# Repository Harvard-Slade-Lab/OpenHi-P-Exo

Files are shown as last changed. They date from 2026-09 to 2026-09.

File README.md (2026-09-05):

# OpenHi-P Exoskeleton
Open-source, High-torque, and Portable (OpenHi-P) hip exoskeleton

Supplementary materials for "an open-source, high-torque, and portable hip exoskeleton for physically demanding locomotion."

This repository contains the STM32 controller firmware, the hardware resources, and the
host-PC human-in-the-loop optimization pipeline.

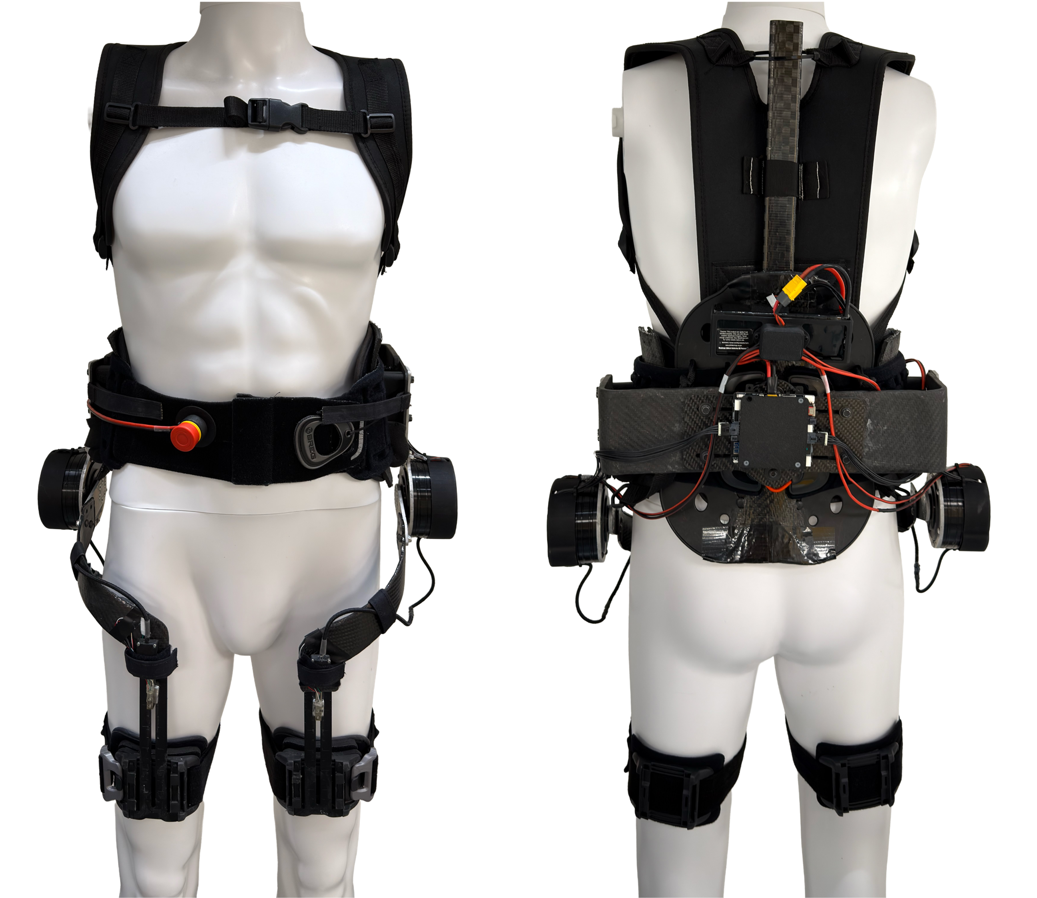
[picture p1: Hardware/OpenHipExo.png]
OpenHipExo Hardware


## Software Overview

This repository contains two pieces of software: the human-in-the-loop optimization that
runs on a host PC, which measures metabolic cost and searches for the torque profile that
minimizes it, and the embedded controller that runs on the exoskeleton, which applies that
torque profile in real time. The two communicate over Bluetooth Low Energy (BLE).

| Runs on | Directory | Language / toolchain |
|---|---|---|
| **Host PC** (Windows) — human-in-the-loop optimization | `Optimizer/` | Python, conda (`Optimizer/metcma.yml`) |
| **Exoskeleton** (STM32 microcontroller) — embedded real-time control | `Controller/` | C, STM32CubeIDE 1.17.0 |

Hardware resources for building the device are in `Hardware/`.

## Repository Structure

- `Controller/`  
  Main STM32CubeIDE C source files (core files):
  - `main.c`
  - `control_logic.c`
  - `motor_control.c` 
  - `imu_processing.c`
  - `servo_receiving.c`
  - `servo_sending.c`
  - `torque_profile.c`
  - `torque_calculation.c`
  - `can_rx_callback.c`
  - `globals.c`
  - `sd_card.c`

- `Hardware/`  
  Hardware build resources:
  - `CAD/` : CAD files
  - `Hip Exoskeleton Hardware Building Guide.pdf` : Hardware building guide  

- `Optimizer/`  
  Host-PC human-in-the-loop (HILO) optimization pipeline (Python, flat layout):
  - `main.py` : entry point (BLE + metabolics + controller + GUI)
  - `cma_optimizer.py` : CMA-ES implementation
  - `hiloMetCmaController.py` : condition sequencing and parameter update logic
  - `metabolics_collect.py`, `metabolics_extract.py` : COSMED metabolic data collection and rate estimation
  - `bleFunctions.py` : BLE client and torque-parameter packet protocol
  - `serialPlotter.py`, `param_utils.py`, `timer_manager.py` : live plotting and parameter/timing utilities
  - `metcma.yml` : pinned conda environment

## Controller (Firmware)

- Source code is organized under `Src/`.
- IDE: STM32CubeIDE (Version: 1.17.0)
- Language: C
- The firmware includes gait cycle estimation, desired torque tracking, CAN and Bluetooth communication, and SD card data logging.

## Hardware

- Hardware-related files are located in `Hardware/`.  
- Software: SolidWorks (Version: 2022).
- For detailed instructions on BoM and assembly, see `Hip Exoskeleton Hardware Building Guide.pdf`.
- Commercial off-the-shelf parts (McMaster-Carr fasteners and the CubeMars AK10-9 actuator) are
  not redistributed here. Download them from their vendors to open the full assembly; see
  `Hardware/CAD/README.md` for the part numbers and the file names the assembly expects.

## Optimizer (Host PC)

- Human-in-the-loop optimization code is located in `Optimizer/`.
- Language: Python; dependencies pinned in `Optimizer/metcma.yml`.
- Platform: Windows only (uses Win32 screen capture for the COSMED Omnia window).
- Implements CMA-ES optimization of the torque profile driven by real-time metabolic
  cost, plus the BLE parameter-update protocol to the exoskeleton controller.
- Run with `python main.py`; see `Optimizer/README.md` for installation, Tesseract OCR
  setup, usage, and simulation mode.

## License

This project is released under the MIT License; see `LICENSE`. The license covers
the firmware in `Controller/Core/`, the host-PC optimization code in `Optimizer/`,
and the hardware design files in `Hardware/CAD/` that were created for this project.

Two exceptions:

- Third-party components vendored under `Controller/Drivers/` and
  `Controller/Middlewares/` remain under their own licenses. CMSIS is Apache-2.0,
  the STM32F4xx HAL driver is BSD-3-Clause, and FatFs is under the ChaN one-clause
  BSD license. CMSIS and the HAL driver carry their own LICENSE.txt; the FatFs terms
  are stated in the headers of its source files.
- Commercial off-the-shelf CAD models are not redistributed here and are not covered
  by this license; see `Hardware/CAD/README.md`.

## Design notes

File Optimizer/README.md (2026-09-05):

# Hip-Exo-Optimization — Human-in-the-Loop (HILO) Metabolic Optimizer

PC-side software that runs **human-in-the-loop optimization** of a hip-exoskeleton
torque profile using **CMA-ES**, driven by **real-time metabolic cost** measured
from a COSMED indirect-calorimetry system. The PC ranks candidate torque profiles,
updates the CMA-ES search distribution, and streams new parameters to the
exoskeleton controller over **Bluetooth Low Energy (BLE)**.

Everything in this directory runs on the **Windows host PC**. The embedded controller
that drives the motors runs on the exoskeleton's **STM32**, from the firmware in
[`../Controller/`](../Controller/) of this same repository. The two communicate only
over BLE: the PC sends a torque-profile parameter packet, and the exoskeleton applies it.

**Affiliation:** Harvard Slade Lab
**Authors:** Jae Choi, Yinkai Dong

---

## Installation

**Platform: Windows only.** 

**1. Get the code**
```bash
git clone https://github.com/Harvard-Slade-Lab/OpenHi-P-Exo.git
cd OpenHi-P-Exo/Optimizer
```

**2. Create the conda environment** (pinned in `metcma.yml`)
```bash
conda env create -f metcma.yml
conda activate metcma
```

**3. Install Tesseract OCR** (reads numbers off the Omnia screen). Download the
preconfigured package
([Google Drive](https://drive.google.com/file/d/17DEtPNnrKnunzDX3ql_moAN2LRDF_OS9/view?usp=sharing))
and extract it into this directory so that `Tesseract-OCR/tesseract.exe` exists —
`metabolics_extract.py` resolves this path relative to its own location.

For a full hardware run you also need a BLE adapter, the exoskeleton advertising as
`HIP_EXO_MAIN`, and a COSMED metabolic cart with the Omnia window visible on screen.

---

## Usage

```bash
python main.py
```

It will:

1. Prompt for **subject number** and **body weight (kg)**.
2. Connect to the exoskeleton over BLE (device name `HIP_EXO_MAIN`) and wait until
   connected.
3. Ask you to draw three OCR regions on the Omnia window — **Time, VO2, VCO2**.
4. Open a **PyQt5 + pyqtgraph** GUI with live plots and **Start / Stop / Skip**
   buttons, then run the CMA-ES optimization of the torque profile.

- **Start** begins the CMA-ES loop; **Stop** aborts the current condition and
  ramps torque to zero (BLE stays up); **Skip** discards the current condition.
- **Resuming:** if a subject's `cmaLogFile.csv` already exists, the run reloads the
  saved CMA-ES state and continues.
- **Simulation mode (no hardware):** set `metUse = False` (and `bleUse = False`) in
  `main.py` to run the full loop on synthetic breaths.

---

## Repository structure

```
OpenHi-P-Exo/Optimizer/
│
├── main.py                    # Entry point: wires BLE + OCR + controller + GUI
├── hiloMetCmaController.py    # Central coordinator (HILOMetCmaController)
├── cma_optimizer.py           # CMA-ES optimizer
├── metabolics_collect.py      # Metabolics collection loop
├── metabolics_extract.py      # Screen capture + OCR of the Omnia display
├── bleFunctions.py            # BLE client and torque-parameter protocol
├── serialPlotter.py           # Real-time visualization (PyQtGraph)
├── param_utils.py             # Torque-profile parameter handling
├── timer_manager.py           # Qt timer helper
├── metcma.yml                 # Pinned conda environment
├── (Tesseract-OCR/)           # Installed separately, see step 3
└── README.md
```

Runtime output is written under `outcmaes/subject_<N>/` (per-condition
CSV log, pickled CMA-ES state + backups, per-breath metabolics CSVs, and plot PNGs).

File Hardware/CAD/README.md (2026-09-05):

# CAD files

This folder contains the parts designed for the OpenHi-P exoskeleton: the custom
SolidWorks parts, the `DWG/` drawings for machined parts, and the `STL/` files for
printed parts and molds.

## Commercial off-the-shelf parts are not included

The fasteners and the actuator model are commercial parts supplied by their vendors,
so their CAD files are not redistributed here. `Assmebly.SLDASM` still references them,
and SolidWorks will report them as missing until you supply them yourself.

To open the full assembly, download each part from its vendor and save it into this
folder. **SolidWorks resolves references by file name, so save each file under exactly
the name listed below** and the assembly will rebuild without further edits.

### McMaster-Carr fasteners

Download from [mcmaster.com](https://www.mcmaster.com) by searching the part number.

| Part number | Description | Save as |
|---|---|---|
| 91116A350 | 18-8 Stainless Steel Oversized Washer | `91116A350_18-8 Stainless Steel Oversized Washer.SLDPRT` |
| 91116A360 | 18-8 Stainless Steel Oversized Washer | `91116A360_18-8 Stainless Steel Oversized Washer.SLDPRT` |
| 91239A144 | Button Head Hex Drive Screw | `91239A144_Button Head Hex Drive Screw.SLDPRT` |
| 91239A232 | Button Head Hex Drive Screw | `91239A232_Button Head Hex Drive Screw.SLDPRT` |
| 91239A318 | Button Head Hex Drive Screw | `91239A318_Button Head Hex Drive Screw.SLDPRT` |
| 91251A345 | Black-Oxide Alloy Steel Socket Head Screw | `91251A345_Black-Oxide Alloy Steel Socket Head Screw.SLDPRT` |
| 91253A197 | Black-Oxide Alloy Steel Hex Drive Flat Head Screw | `91253A197_Black-Oxide Alloy Steel Hex Drive Flat Head Screw.SLDPRT` |
| 91294A192 | Black-Oxide Alloy Steel Hex Drive Flat Head Screw | `91294A192_Black-Oxide Alloy Steel Hex Drive Flat Head Screw.SLDPRT` |
| 94645A102 | High-Strength Steel Nylon-Insert Locknut | `94645A102_High-Strength Steel Nylon-Insert Locknut.SLDPRT` |
| 95947A560 | Aluminum Female Threaded Hex Standoff | `95947A560_Aluminum Female Threaded Hex Standoff.SLDPRT` |
| 97131A120 | Medium-Strength Nylon-Insert Locknut | `97131A120_Medium-Strength Nylon-Insert Locknut.SLDPRT` |
| 98093A211 | Black-Phosphate Class 10.9 Steel Hex Head Screw | `98093A211_Black-Phosphate Class 10.9 Steel Hex Head Screw.SLDPRT` |
| 98093A212 | Black-Phosphate Class 10.9 Steel Hex Head Screw | `98093A212_Black-Phosphate Class 10.9 Steel Hex Head Screw.SLDPRT` |
| 98093A310 | Black-Phosphate Class 10.9 Steel Screw | `98093A310_Black-Phosphate Class 10.9 Steel Screw.SLDPRT` |
| 98093A316 | Black-Phosphate Class 10.9 Steel Hex Head Screw | `98093A316_Black-Phosphate Class 10.9 Steel Hex Head Screw.SLDPRT` |
| 98370A009 | 18-8 Stainless Steel Oversized Washer | `98370A009_18-8 Stainless Steel Oversized Washer.SLDPRT` |

### Actuator

| Part | Source | Save as |
|---|---|---|
| CubeMars AK10-9 V2.0 | CubeMars product page | `AK10-9.SLDPRT` |

Quantities and the rest of the bill of materials are in
`../Hip Exoskeleton Hardware Building Guide.pdf`.

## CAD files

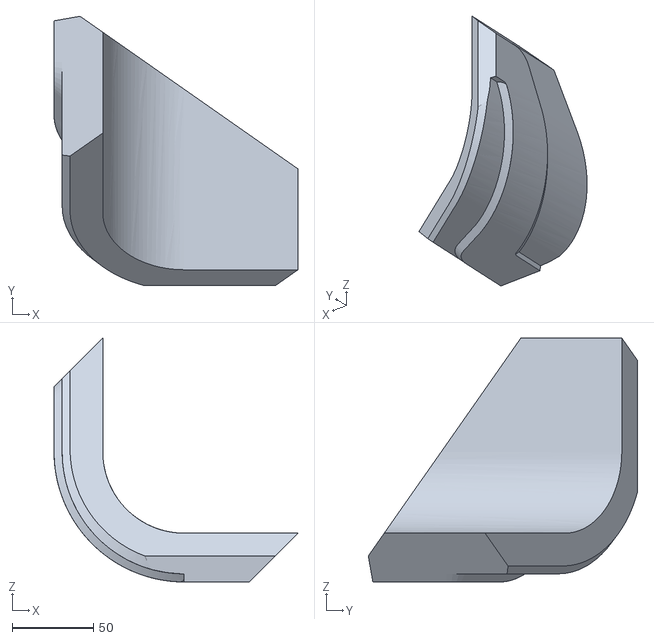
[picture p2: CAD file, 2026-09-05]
Hardware/CAD/STL/Thigh_strut_mold_left.STL
150.0 x 165.6 x 150.0

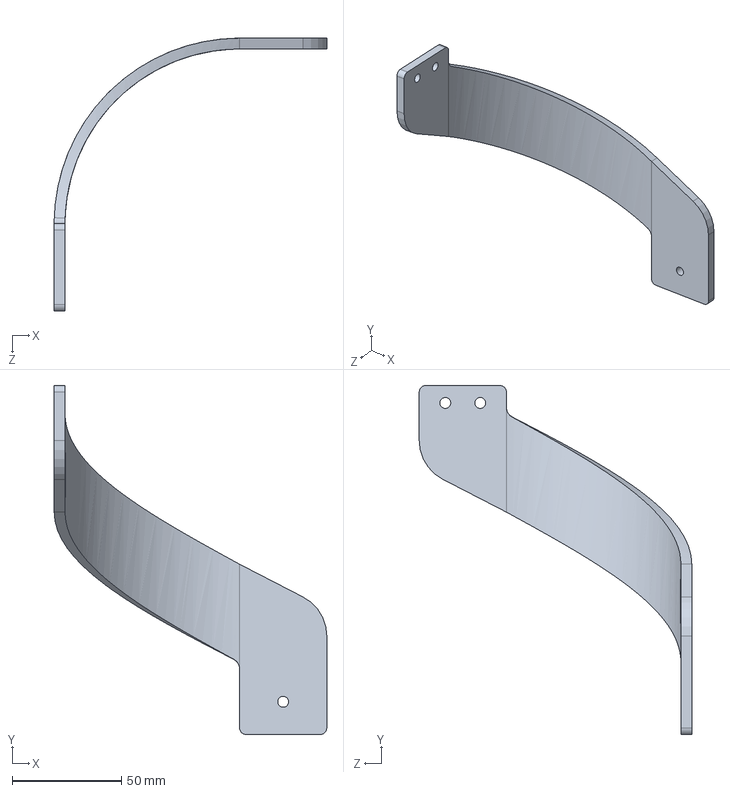
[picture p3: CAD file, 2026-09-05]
Hardware/CAD/Thigh_strut_left.SLDPRT
125.0 x 160.0 x 125.0 mm

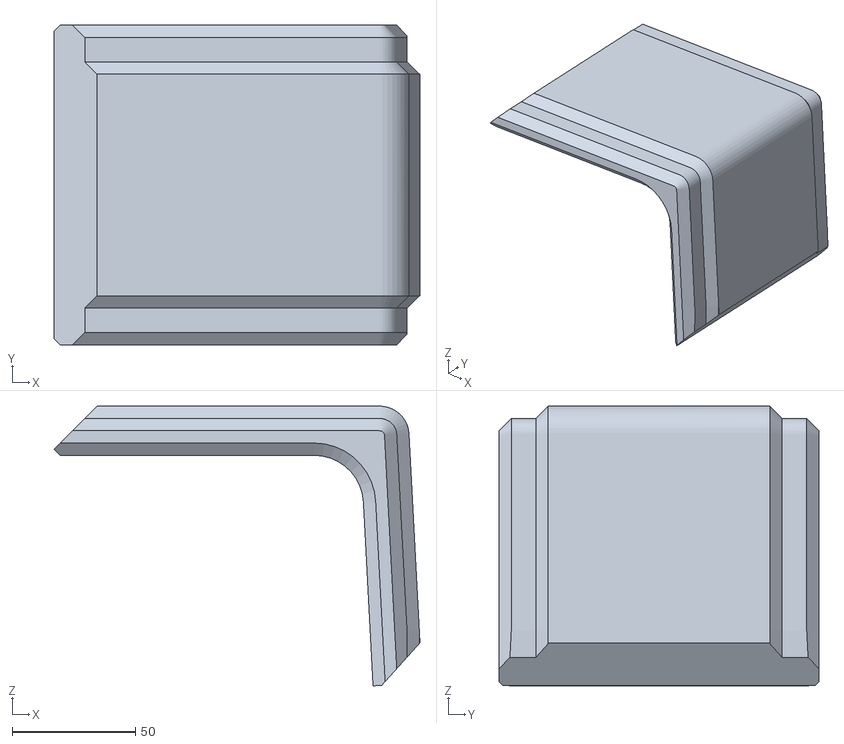
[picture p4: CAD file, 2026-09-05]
Hardware/CAD/STL/Waist_c_frame_mold.STL
148.7 x 130.0 x 113.6

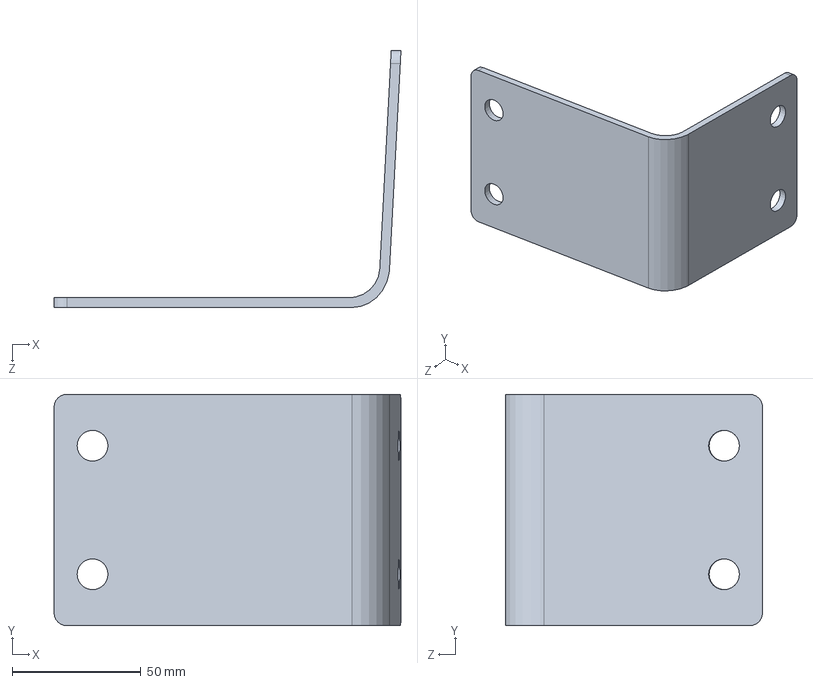
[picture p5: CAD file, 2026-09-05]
Hardware/CAD/Waist_c_frame.SLDPRT
135.0 x 90.0 x 100.0 mm

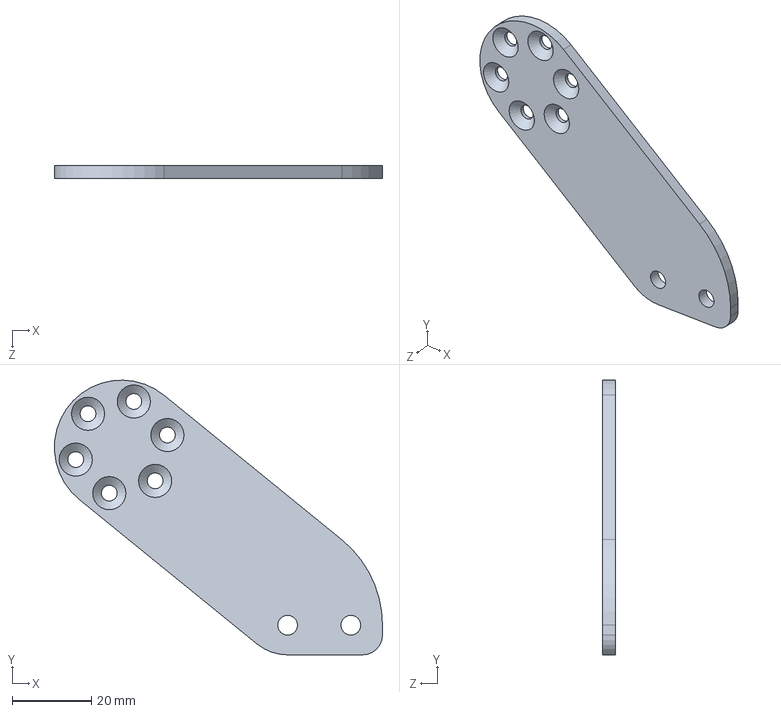
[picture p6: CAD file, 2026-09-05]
Hardware/CAD/Motor_rotor_left.SLDPRT
83.0 x 69.5 x 3.17 mm

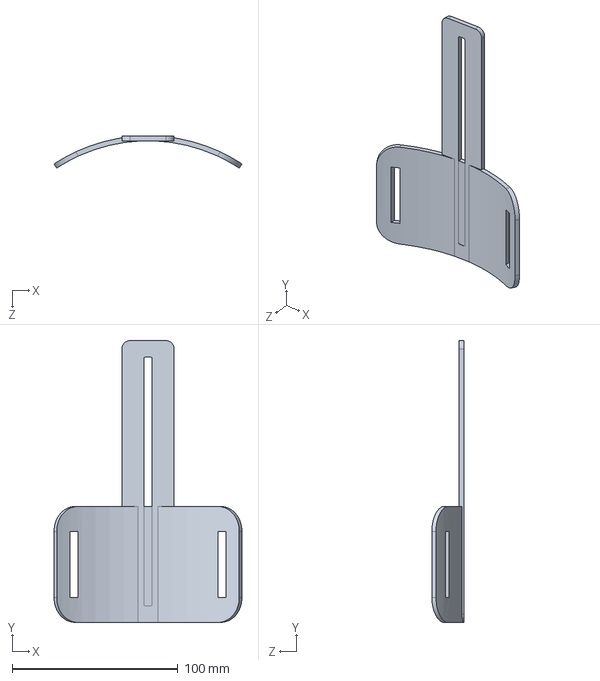
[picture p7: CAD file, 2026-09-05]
Hardware/CAD/Thigh_brace.SLDPRT
113.3 x 170.0 x 19.5 mm

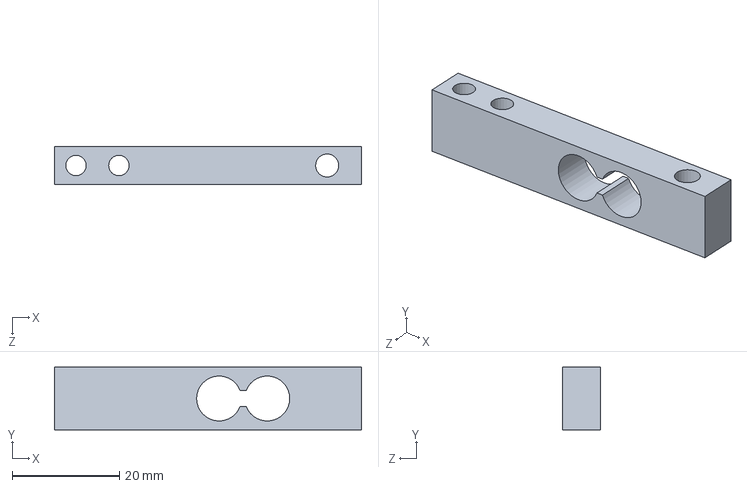
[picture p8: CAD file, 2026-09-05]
Hardware/CAD/Loadcell.SLDPRT
57.2 x 11.7 x 7.00 mm

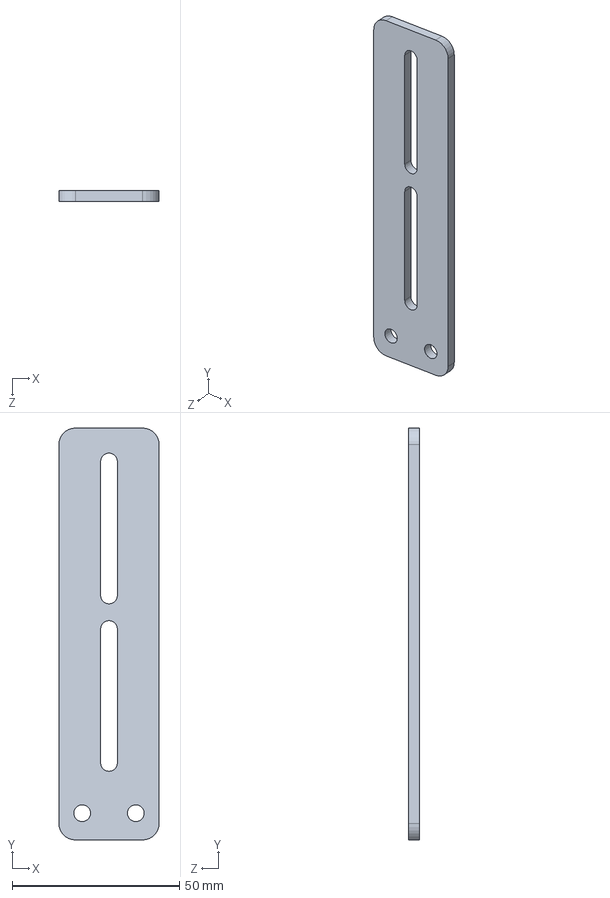
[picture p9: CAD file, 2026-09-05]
Hardware/CAD/Motor_stator_strut.SLDPRT
30.0 x 123.0 x 3.17 mm

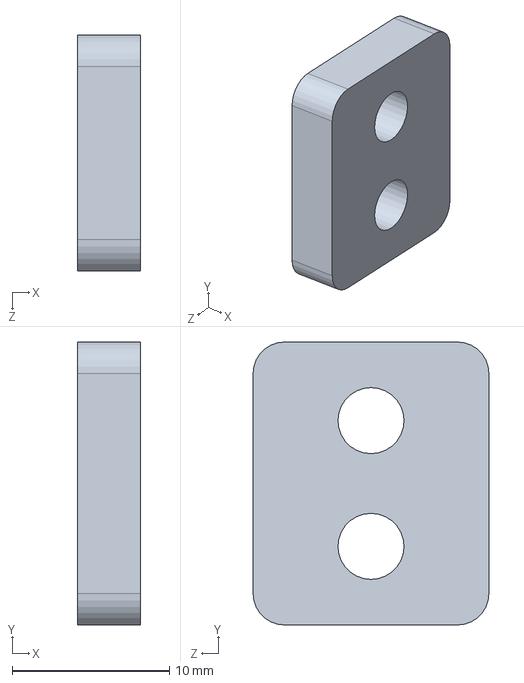
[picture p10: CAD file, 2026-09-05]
Hardware/CAD/Loadcell_bumper_t.SLDPRT
4.00 x 18.0 x 15.0 mm

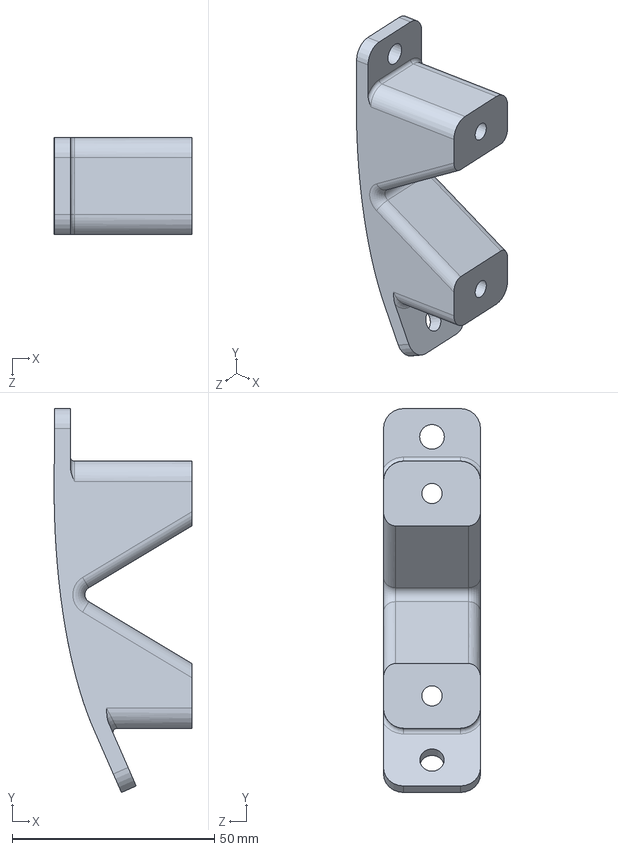
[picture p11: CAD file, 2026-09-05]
Hardware/CAD/Waist_side_connector.SLDPRT
34.0 x 94.9 x 24.0 mm

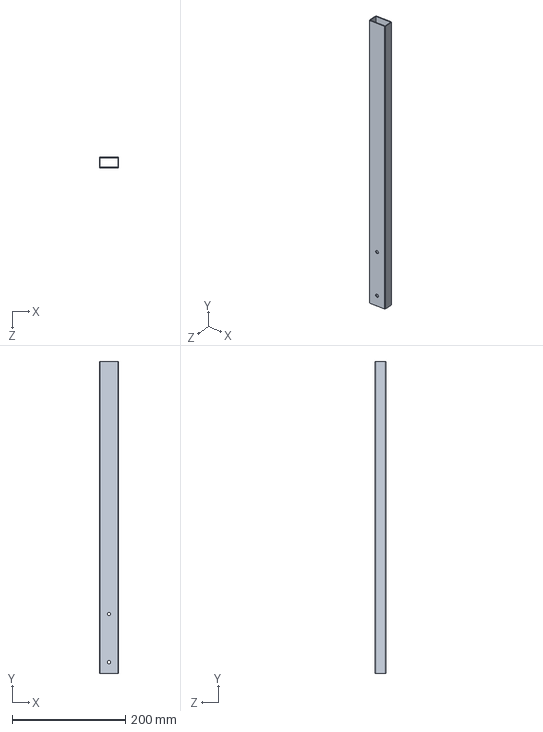
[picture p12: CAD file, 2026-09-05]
Hardware/CAD/Back_strut.SLDPRT
34.3 x 550.0 x 19.1 mm

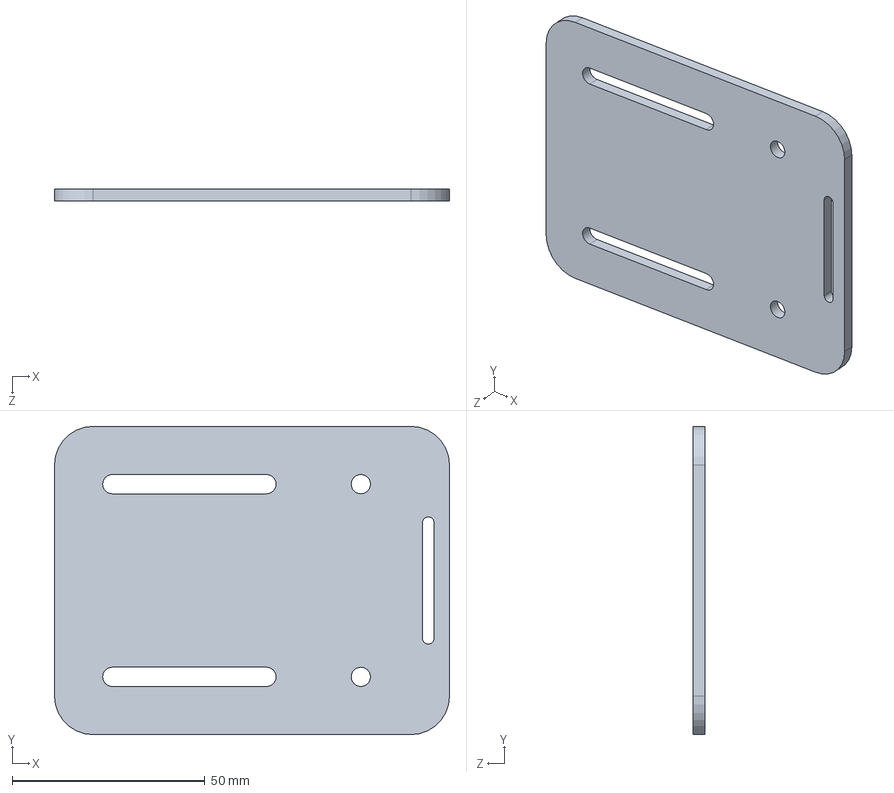
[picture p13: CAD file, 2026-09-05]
Hardware/CAD/Waist_side_plate.SLDPRT
102.5 x 80.0 x 3.17 mm

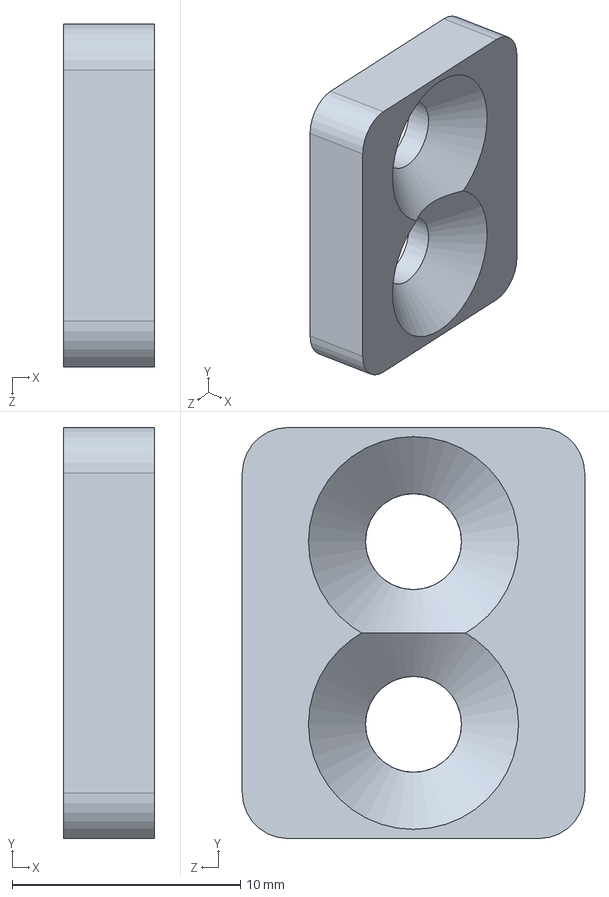
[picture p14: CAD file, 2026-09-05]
Hardware/CAD/Loadcell_bumper_b.SLDPRT
4.00 x 18.0 x 15.0 mm

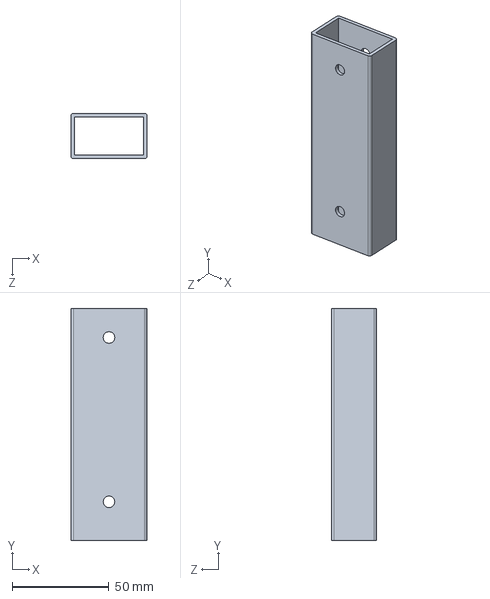
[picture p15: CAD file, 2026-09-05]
Hardware/CAD/Cf_tube_hole_reference.SLDPRT
39.5 x 120.0 x 23.5 mm

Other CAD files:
Hardware/CAD/DWG/Loadcell_bumper.DWG
Hardware/CAD/DWG/Motor_rotor.DWG
Hardware/CAD/STL/Thigh_strut_mold_right.STL
Hardware/CAD/Motor_rotor_right.SLDPRT
Hardware/CAD/DWG/Motor_stator.DWG
Hardware/CAD/DWG/Motor_stator_strut.DWG
Hardware/CAD/DWG/Waist_back_plate.DWG
Hardware/CAD/DWG/Waist_side_plate.DWG
Hardware/CAD/Insert.SLDPRT
Hardware/CAD/Motor_stator.SLDPRT
Hardware/CAD/STL/Cf_tube_hole_reference.STL
Hardware/CAD/STL/Insert.STL
Hardware/CAD/STL/Waist_side_connector.STL
Hardware/CAD/Thigh_strut_right.SLDPRT
Hardware/CAD/Waist_back_plate.SLDPRT

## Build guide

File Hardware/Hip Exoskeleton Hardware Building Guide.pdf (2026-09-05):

# Hardware building guide for an Open-source, High-torque, and Portable (OpenHi-P) hip exoskeleton

Jae-Ryeong Choi, Yinkai Dong, Catherine Rohner, and Patrick Slade

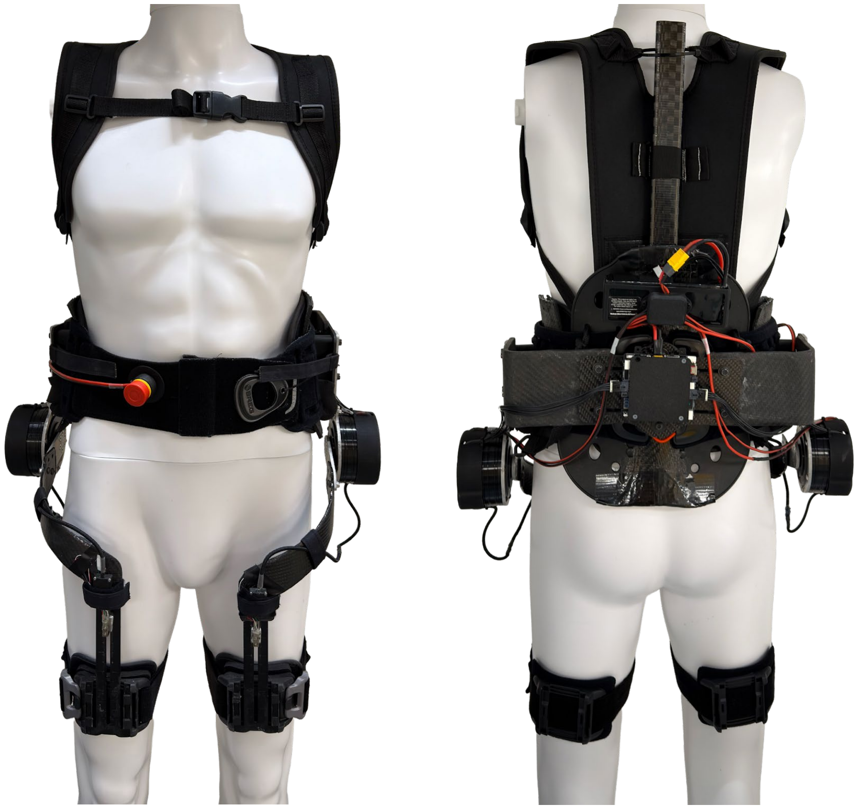
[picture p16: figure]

# Bill of materials

## Commercially available goods

COM-1: Vest: Smith Performance Sprayer (https://www.amazon.com/Smith-Performance-Sprayers-182943-Backpack/dp/B01MY1YLJZ?hvadid=193139379506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) ($39.49) x 1
COM-2: Back brace: Nvorliy LSO Lower Back Brace (https://www.amazon.com/Nvorliy-Lower-Back-Brace-Decompression/dp/B09MPKXBKF) ($38.99) x 1 COM-3: Hip brace: Breg T-scope hip brace (https://www.breg.com/products/hip-bracing/hip-bracing-post-op/t-scope-hip-brace/) (used) x 2

## Electronics and power

ELE-1: Motor: Cubemars AK10-9 V2.0 KV60 (https://www.cubemars.com/product/ak10-9-v2-0-kv60-robotic-actuator.html) ($798.90) x 2 ELE-2: Load cell: SMD S230 (https://www.smdsensors.com/products/type/s230-low-profile-load-cell/?highlight=s230) ($210.94) x 2
ELE-3: IMU: Xsens MTi-3-5A-T (https://www.digikey.com/en/products/detail/xsens-a-movella-brand/MTI-3-5A-T/18718048) ($359) x 2
ELE-4: Controller: STM32 Nucleo-F446RE (https://www.digikey.com/en/products/detail/stmicroelectronics/NUCLEO-F446RE/5347712) ($14.85) x 1
ELE-5: Battery: MaxAmps LiPo 3250mAh 6S 22.2v Battery Pack (https://maxamps.com/collections/6s-lipo-battery-22-2v/products/lipo-3250-6s-22-2v-battery-pack) ($210) x 1
ELE-6: Emergency stop: Galco XA1E-BV3SG01RH (https://www.galco.com/xa1e-bv3sg01rh-idec.html) ($44.93) x 1

## Items for fabrication

FAB-1: Carbon fiber plate: DragonPlate EconomyPlate™ ~ 1/8" x 24" x 24" (https://dragonplate.com/economyplate-solid-carbon-fiber-sheet-3mm-x-24-x-24) ($337.55) FAB-2: Carbon fiber tube: Rectangle - Spread Tow Fabric - 0.625 x 1.25 - 0.75 x 1.35 x 66 inch (https://www.rockwestcomposites.com/25502-im.html) ($206.99)
FAB-3: Aluminum sheet: 7075-T6 aluminum sheet, 0.16″ × 12″ × 12″ (https://www.mcmaster.com/products/aluminum-slabs/material%7E7075-aluminum/thickness%7E0-160/width%7E12/length%7E12/length%7E1-ft/) ($54.9)
FAB-4: Velcro: Extra-Wide Hook and Loop
A. Loop: VELCRO Brand Sew On Loop, 4″ x 900″ (https://www.hookandloop.com/brands/velcro/sew-on) ($ 76)
B. Hook: VELCRO Brand Sew On Hook, 4″ x 900″ (https://www.hookandloop.com/brands/velcro/sew-on) ($ 76)
FAB-5: Foam Padding: Adhesive-backed Neoprene Sheet, 12″ × 59″ × 1/2″ (https://www.amazon.com/FONUNO-Adhesive-Insulation-Neoprene-Projects/dp/B0FPFT157Q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) ($26.99) FAB-6: Carbon fiber sheet: Carbon Fiber Fabric 2x2 Twill 6k 11oz/372gsm (https://www.compositeenvisions.com/Carbon-Fiber-Fabric-2x2-Twill-6k-11oz-373gsm-Commercial-Grade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) ($42.48) FAB-7: Epoxy resin: WEST SYSTEM 105B Bundle with 205B Fast Epoxy Hardener (https://www.amazon.com/System-105-B-Epoxy-Hardener-Metering/dp/B07JKYCV8G) ($203.22)
FAB-8: Vacuum bag: Vacuum Compression Space Saving Storage Bags (https://www.amazon.com/AmazonBasics-Vacuum-Compression-Storage-Bags/dp/B07RSCK4XS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) ($17.48) FAB-9: Peel ply: ZENFUN Cloth Carbon Fiber Fiberglass 5 Yard 30 Inch (https://www.amazon.com/ZENFUN-Fiber-Fiberglass-Temperature-Compatible/dp/B0FMRNBF7K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) ($15.99) FAB-10: Breather-bleeder fabric: Fibre Glast (polyester), ~60" × 36" (1 yard) (https://www.amazon.com/Fibre-Glast-Ounce-Breather-Bleeder/dp/B015NM0B8K) ($13.95) FAB-11: Release film: Fibre Glast Low Temp Release Film (https://www.amazon.com/Fibre-Glast-Temperature-Release-Film/dp/B015NM4OEW?sp_csd=d2lkZ2V0TmFtZT1zcF9hdGY) ($10.95)

## Fasteners

Standoff:
STF-1: Lightweight Aluminum Female Threaded Hex Standoff (https://www.mcmaster.com/95947A560/)
Bolts:
BLT-1: Flanged Button Head Screws, M6 x 1.00 mm Thread, 35mm Long (https://www.mcmaster.com/92137A550/) BLT-2: Hex Head Screw Flanged, M5 x 0.8 mm Thread Size, 16 mm Long (https://www.mcmaster.com/98093A316/) BLT-3: Button Head Hex Drive Screw, Black-Oxide Alloy Steel, M5 x 0.80 mm Thread, 6 mm Long (https://www.mcmaster.com/91239A220/)
BLT-4: Nylon Pan Head Phillips Screws M3 x 0.50 mm Thread, 25mm (https://www.mcmaster.com/92492A723/) BLT-5: Button Head Hex Drive Screw, Black-Oxide Alloy Steel, M6 x 1.00 mm (https://www.mcmaster.com/91239A318/)

Thread, 12 mm Long (https://www.mcmaster.com/91239A318/)
BLT-6: Black-Oxide Alloy Steel Hex Drive Flat Head Screw 8-32 Thread Size, 3/4" Long (https://www.mcmaster.com/91253a197/)
BLT-7: Black-Oxide Alloy Steel Socket Head Screw 10-32 Thread Size, 3/4" Long (https://www.mcmaster.com/91251A345/) BLT-8: Zinc-Plated Alloy Steel Hex Drive Flat Head Screw M4 x 0.7 mm Thread Size, 10 mm Long (https://www.mcmaster.com/91263A828/)
BLT-9: Button Head Hex Drive Screw Black-Oxide Alloy Steel, M4 x 0.70 mm Thread, 10 mm Long (https://www.mcmaster.com/91239A144/)
BLT-10: Black-Phosphate Class 10.9 Steel Hex Head Screw Flanged, M5 x 0.8 mm Thread Size, 25 mm Long (https://www.mcmaster.com/98093A212/)
Nuts:
NUT-1: Zinc-Plated Steel M5 x 0.8 mm (https://www.mcmaster.com/94645A102/)
NUT-2: Nylon Hex Nut M3 x 0.5 mm Thread (https://www.mcmaster.com/93800A400/)
Washer:
WSR-1: Stainless Steel Oversized Washer, 5.3 mm ID, 15.0 mm OD (https://www.mcmaster.com/91116A350/) WSR-2: Stainless Steel Oversized Washer, 6.4 mm ID, 18.0 mm OD (https://www.mcmaster.com/91116A360/) WSR-3: Stainless Steel Oversized Washer 0.172" ID, 0.375" OD (https://www.mcmaster.com/98370A009/)

# Fabrication methods

## Carbon-fiber composite molding

Components:
- CF-1: Thigh_strut_mold_left.stl, Thigh_strut_mold_right.stl
- CF-2: Waist_c_frame_mold.stl
- CF-3: COM-2 reinforcement
Steps:
1. Print molds (Thigh_strut_mold_left.stl, Thigh_strut_mold_right.stl, and Waist_c_frame_mold.stl). Cover all mold surfaces with release film to prevent epoxy adhesion and to facilitate demolding after curing.
2. Cut the carbon fiber sheets, peel ply, and breather fabric to the required geometries. Apply two layers of peel ply to CF-1 and CF-2 to ensure clean release and a consistent surface finish. For CF-3, apply one layer of peel ply. In all cases, apply a single layer of breather fabric to enable air evacuation and absorb excess resin during vacuum compaction.
3. Prepare the epoxy using WEST SYSTEM 105B resin with 205B fast hardener. Mix the components according to the manufacturer’s recommended ratio and stir thoroughly until the mixture is homogeneous to ensure consistent curing. Perform all layups in a chemical fume hood under vacuum bagging conditions to ensure proper resin handling and adequate laminate compaction.
4. For CF-1 and CF-2, first place a layer of peel ply onto the prepared mold surface, then apply a thin, uniform epoxy layer. Use 8 carbon fiber layers for CF-1, 16 layers for CF-2. For CF-3, apply epoxy directly to the central support region of the COM-2 brace, then bond two carbon fiber sheets to both the anterior and posterior surfaces. Use 4 layers for each side of CF-3.
5. Apply carbon fiber sheets sequentially, brushing epoxy between layers to ensure complete saturation and adequate interlaminar bonding. Use a balanced 0°/90°/±45° fiber orientation sequence to provide multidirectional stiffness and improved structural performance under combined loading. After placing the final carbon fiber layer, apply a top layer of peel ply to facilitate unmolding.
6. Cover the laminate stack with breather fabric and enclose it in vacuum bagging film. Seal the vacuum bag and apply vacuum pressure to ensure uniform compaction across the laminate thickness. Inspect the system for leaks and confirm that the bag conforms tightly to the mold geometry. Cure the composite under continuous vacuum at room temperature overnight.
7. Once curing is complete, release the vacuum and remove the composite parts from the bag. Remove the breather fabric, peel ply, and release film, then trim excess material from the edges. Achieve the final edge geometry by grinding and hand-drilling mounting holes according to specification.

## Waterjet cutting

Components:
- Carbon fiber plate (FAB-1, 0.125 inch)
- CUT-CF-1: Waist_back_plate.dwg x 2
- CUT-CF-2: Waist_side_plate.dwg x 2
- Aluminum plate (FAB-3, 0.16 inch)
- CUT-AL-1: Motor_rotor.dwg x 2
- CUT-AL-2: Motor_stator.dwg x 2
- CUT-AL-3: Motor_stator_strut.dwg x 2
- CUT-AL-4: Loadcell_bumper.dwg x 4

## CNC machining

Components:
- Aluminum 7075
- CNC-1: Insert.stl x 4
- After printing, press-fit two NUT-1s into the designated hexagonal recesses.

## 3D-printing

Components:
- 3DP-1: Waist_side_connector.stl x 2
- After printing, press-fit two NUT-1s into the designated hexagonal recesses. Settings:
- Printer: Bambu Lab P1S
- Setup: 0.4 mm nozzle, textured PEI build plate, Infill 100%.
- Print material: Carbon fiber-reinforced PLA (PLA-CF).

## Sewing

Components:
- COM-1
Steps:
1. Remove the waist parts of COM-1. Sew nylon webbing horizontally along both sides of COM-1 to create reinforced attachment points. Secure zip ties around the back rod and the webbing bands to minimize spacing and restrict movement of the carbon fiber rod.
2. Sew an additional strip of nylon webbing along the posterior centerline to guide and stabilize the carbon fiber rod. Reuse the trimmed webbing from the initial fabric removal step for this purpose. Maintain a narrow webbing channel profile to ensure a tight fit with the carbon fiber rod.
3. Sew Velcro to the bottom of COM-1 to complete the lumbar support interface.

## Manual machining

Components:
- Carbon fiber tube cutting (FAB-2)
- CUT-CF-3
■ Cut FAB-2 to 55 cm.
■ Drill two through-holes using the reference model (Cf_tube_hole_reference.stl)
- Load cell tapping (ELE-2)
- Tap two holes for an 8-32 thread (0.15 inch diameter).
- Tap one hole for a 10-32 thread (0.17 inch diameter).
- Countersinking (CUT-AL-2)
- Countersink the flat-head bolt holes.
- COM-2 post-processing
- Drill two M6 holes along the centerline of the brace, spaced 85 mm apart, with the lower hole located 95 mm from the bottom edge.
- Attach the Velcro to the lumbar support side of COM-2.

# Assembly steps

## A1. Back brace and strut integration

Parts needed:
- CUT-CF-3
- COM-2
- BLT-1 x 2
- STF-1 x 2
Steps:
1. Secure CUT-CF-3 to
COM-2 using two BLT-1s and two STF-1s.
2. Trim FAB-4-A to match
the geometry of COM-2-
A and COM-2-B.
3. Bond FAB-4-A to COM-2
to provide a compliant

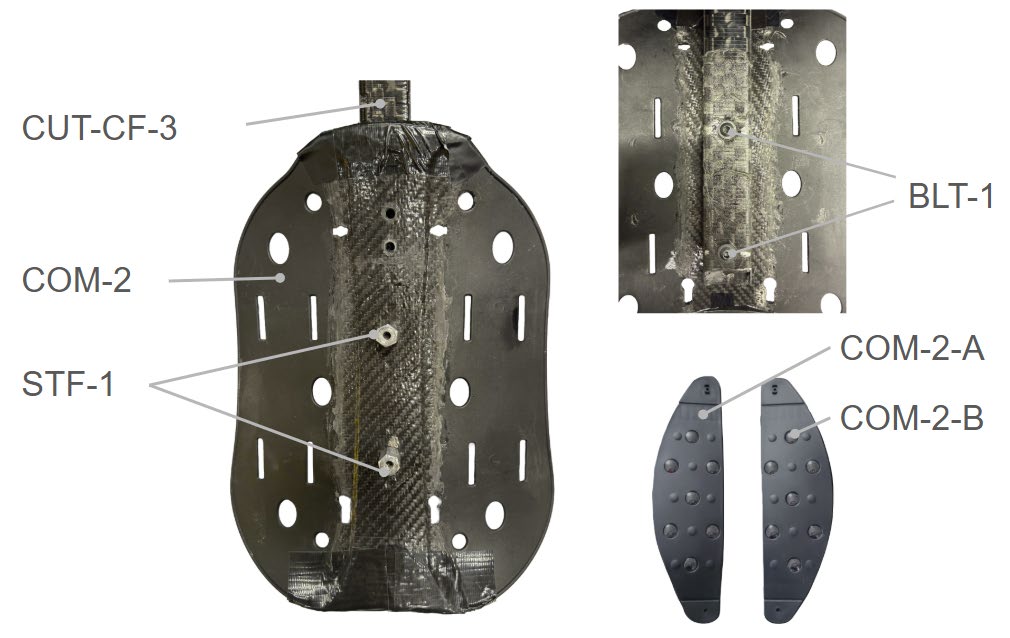
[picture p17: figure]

contact surface and improve load distribution at the lumbar interface.

## A2. A1 and vest integration

Parts needed:
- A1
- COM-1
Steps:
1. Insert CUT-CF-3 (A1) into COM-1.
2. Adjust its vertical position to match the wearer’s torso
length to ensure proper fit and comfort.
3. Thread the COM-1 shoulder
strap webbing through the

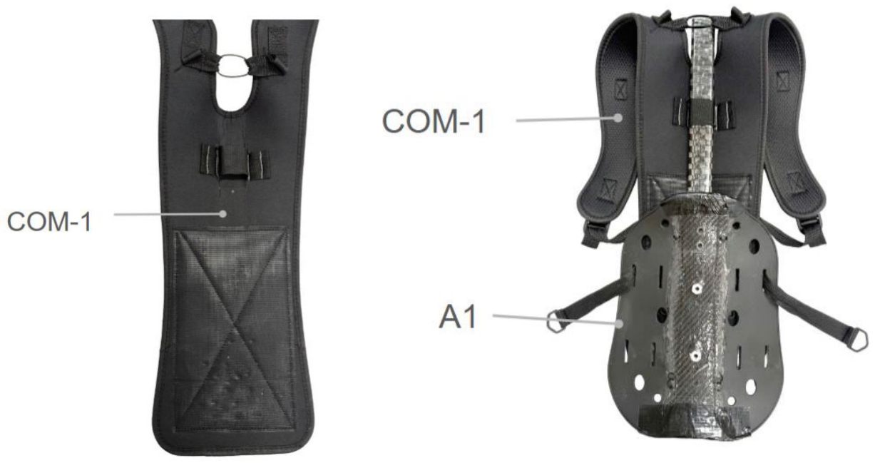
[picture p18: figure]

outer slot on COM-2 (A1) to secure the brace assembly to the vest and maintain alignment during wear.

## B1. Carbon fiber parts integration

Parts needed:
- CUT-CF-1 x 2
- CUT-CF-2 x 2
- CF-2 x 2
- CNC-1 x 4
- WSR-1 x 8
- BLT-2 x 8

Steps:

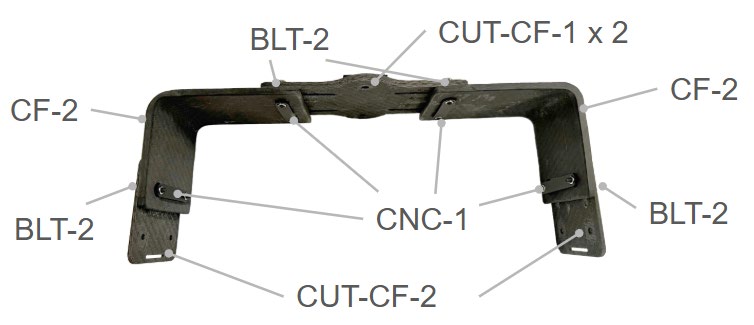
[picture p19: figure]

1. Install the CNC-1 inserts into the corresponding CF-2 components to create reinforced threaded interfaces.
2. Fully overlap and align the two CUT-CF-1 plates to form the central plate structure.
3. Secure each side of this assembly to the CF-2 plates using BLT-2 and WSR-1.
4. Attach the two CUT-CF-2 plates to the opposite sides of the CF-2 plates using the remaining BLT-2 and WSR-1 to complete the carbon fiber plate subassembly.

## C1. Soft waist cover integration

Parts needed:
- COM-3 x 1
- FAB-5
- 3DP-1 x 2
- BLT-3 x 4
- BLT-4 x 4
- NUT-2 x 4

Steps:
1. Secure 3DP-1 to the cavity of
COM-3 using BLT-3.

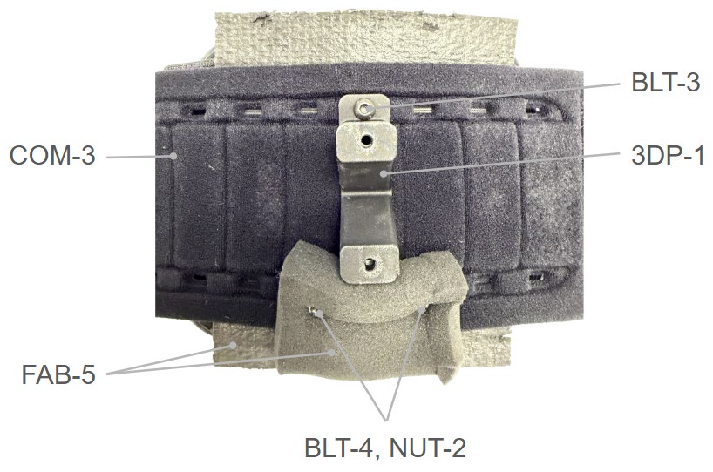
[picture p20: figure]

2. Trim FAB-5 and wrap it around the edge and lower portion of COM-3 to cover both the inner and outer surfaces and to improve pressure distribution during wear.
3. Secure the wrapped FAB-5 layer at the bottom holes using BLT-4 and NUT-2.

## C2. A2, B1, and C1 integration

Parts needed:
- A2
- C1
- B1
- BLT-5 x 2
- WSR-2 x 2

Steps:

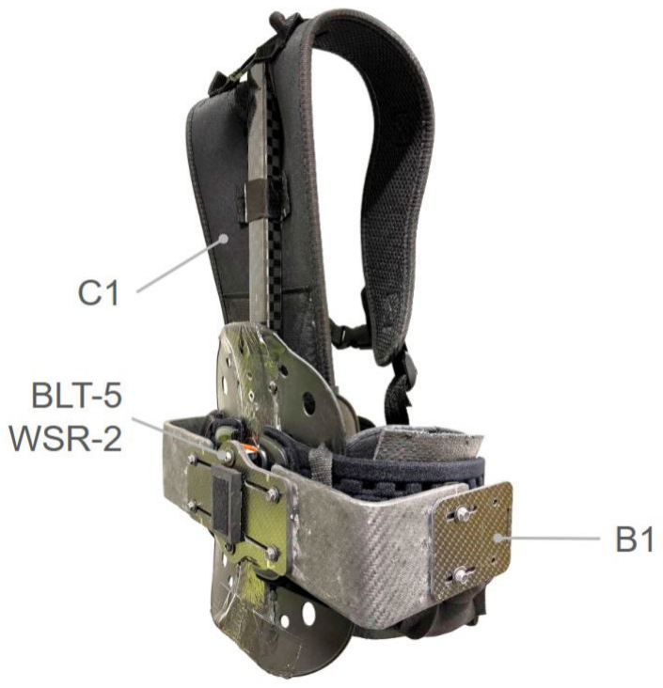
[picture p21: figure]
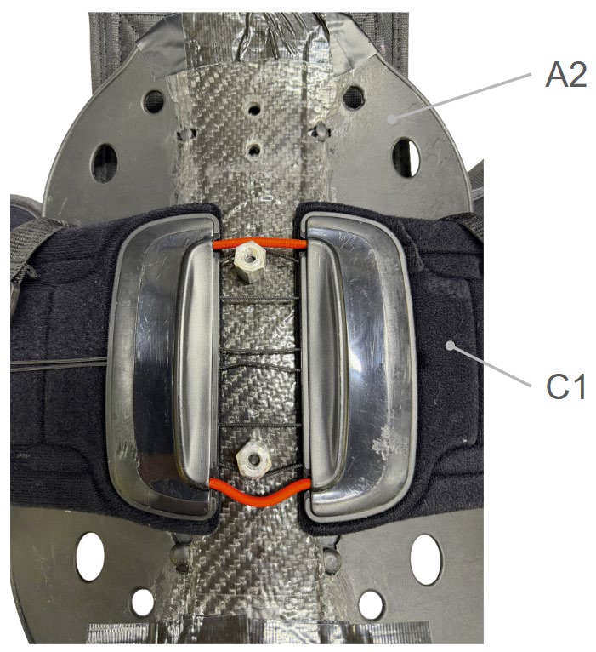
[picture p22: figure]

1. Position C1 on top of A2. Ensure that the STF-1 does not interfere with or compress the routed wires during installation.
2. Secure CUT-CF-1 and STF-1 using BLT-5 and WSR-2.

## D1. Thigh parts integration

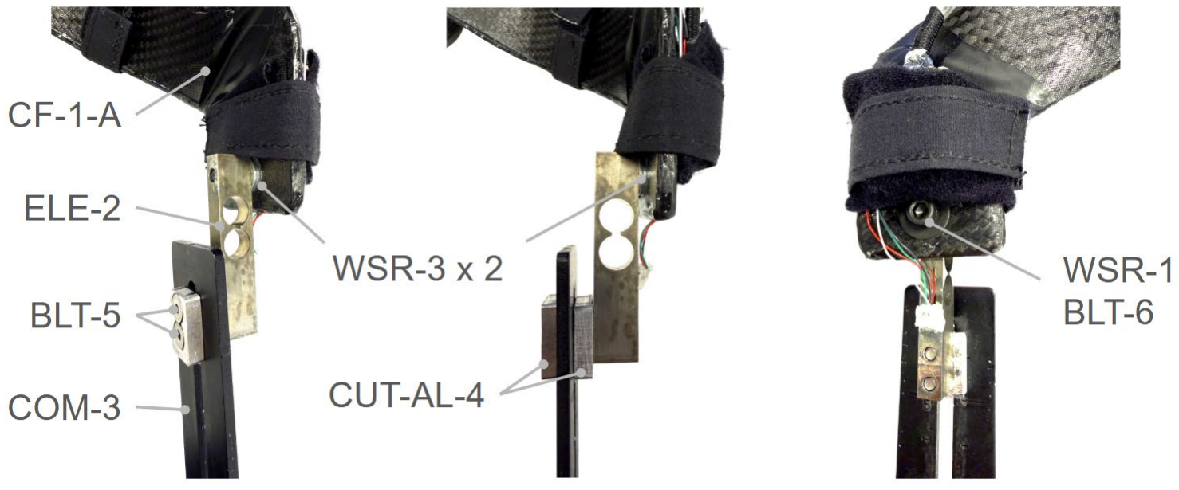
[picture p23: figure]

Parts needed:
- CF-1-A
- CF-1-B
- COM-3
- ELE-2 x 2
- CUT-AL-4 x 4
- BLT-5 x 4
- BLT-6 x 2
- WSR-1 x 2
- WSR-3 x 4
Steps:
1. Stack two WSR-3 in sequence on the side of CF-1-A.
2. Insert BLT-6 through both WSR-3 and CF-1-A, then tighten it into the thread of ELE-2.

## D2. D1 and motor integration

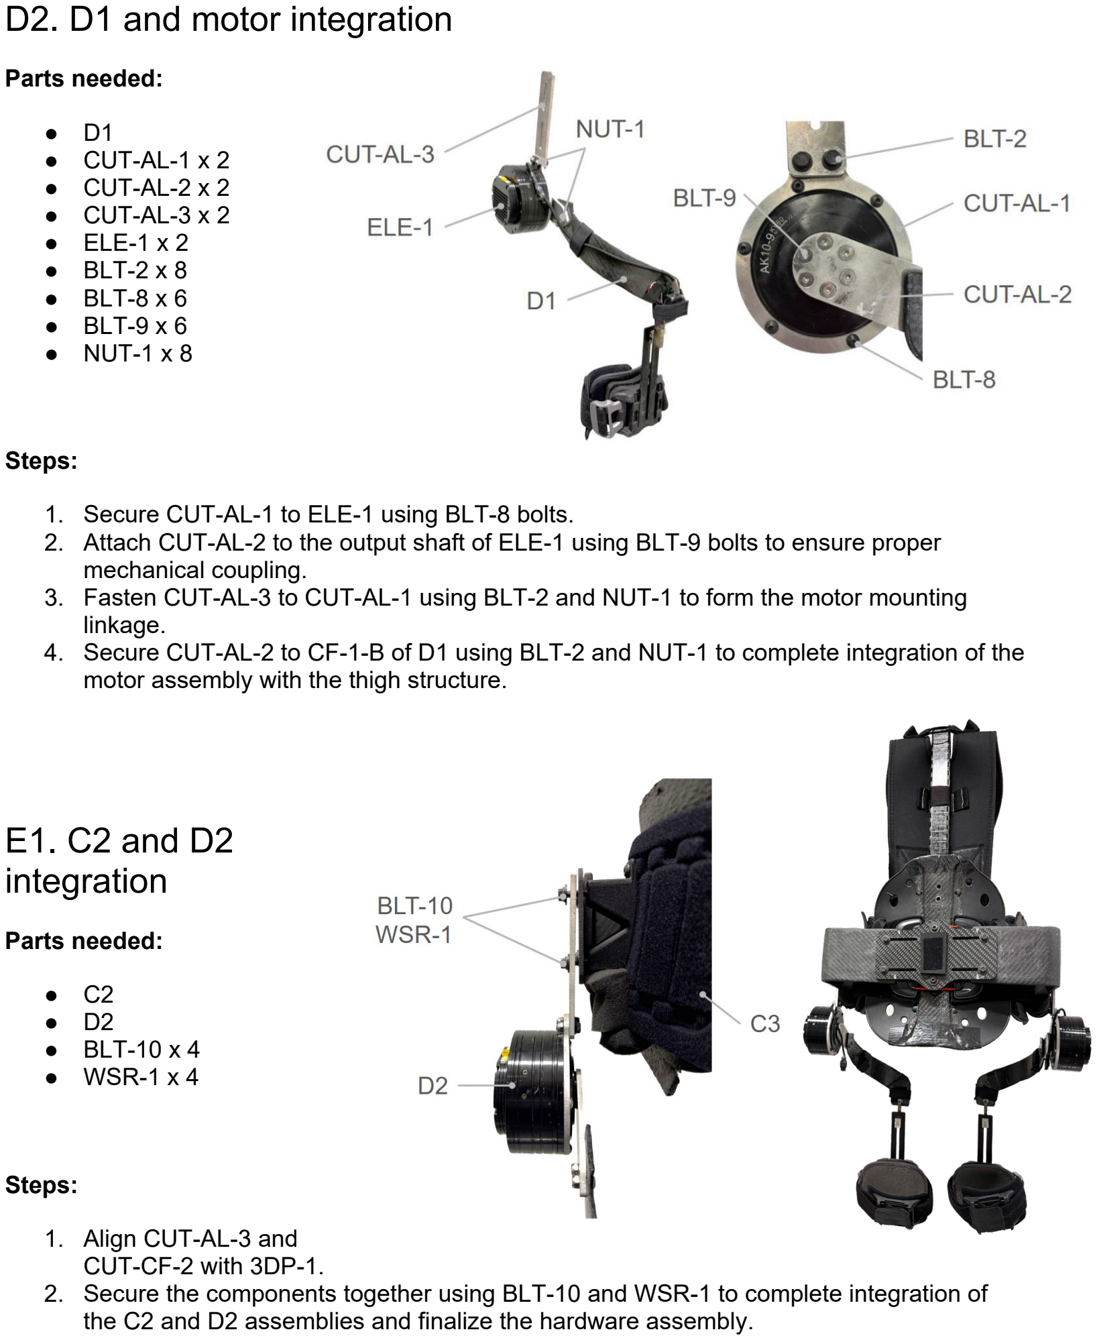
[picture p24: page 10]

Parts needed:
- D1
- CUT-AL-1 x 2
- CUT-AL-2 x 2
- CUT-AL-3 x 2
- ELE-1 x 2
- BLT-2 x 8
- BLT-8 x 6
- BLT-9 x 6
- NUT-1 x 8

Steps:
1. Secure CUT-AL-1 to ELE-1 using BLT-8 bolts.
2. Attach CUT-AL-2 to the output shaft of ELE-1 using BLT-9 bolts to ensure proper mechanical coupling.
3. Fasten CUT-AL-3 to CUT-AL-1 using BLT-2 and NUT-1 to form the motor mounting linkage.
4. Secure CUT-AL-2 to CF-1-B of D1 using BLT-2 and NUT-1 to complete integration of the motor assembly with the thigh structure.

## E1. C2 and D2 integration

Parts needed:
- C2
- D2
- BLT-10 x 4
- WSR-1 x 4

Steps:
1. Align CUT-AL-3 and
CUT-CF-2 with 3DP-1.
2. Secure the components together using BLT-10 and WSR-1 to complete integration of the C2 and D2 assemblies and finalize the hardware assembly.

# Electronics

The OpenHi-P control system is divided into a host-computer layer and an embedded real-time layer.
1. The host PC runs the human-in-the-loop optimization software in the Optimizer directory of the OpenHi-P-Exo repository.
2. The embedded controller runs the C firmware in the Controller directory of the OpenHi-P-Exo repository.
These two software systems communicate through the HM-10 Bluetooth module.

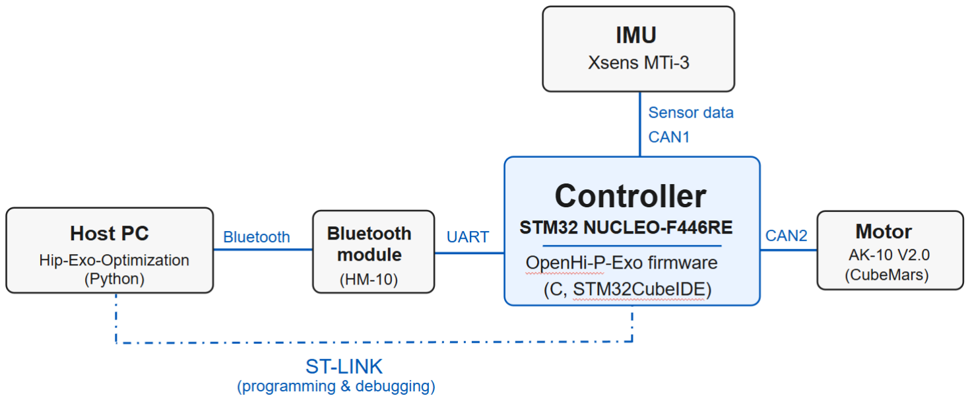
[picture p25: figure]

During an optimization condition:
1. The host PC generates a candidate hip-torque profile and sends the profile over Bluetooth Low Energy.
2. The HM-10 converts the wireless data to a 3.3 V UART stream.
3. The STM32 receives the packet through USART1, updates the active torque profile, estimates gait phase from the sensor signals, and sends motor-current commands through CAN2.

## MCU connection

The embedded controller is the STM32F446RE on the NUCLEO-F446RE development board. The firmware project was created for STM32CubeIDE 1.17.0 and uses the STM32 HAL and FatFs libraries included in the Controller directory. The system clock is configured at 168 MHz.

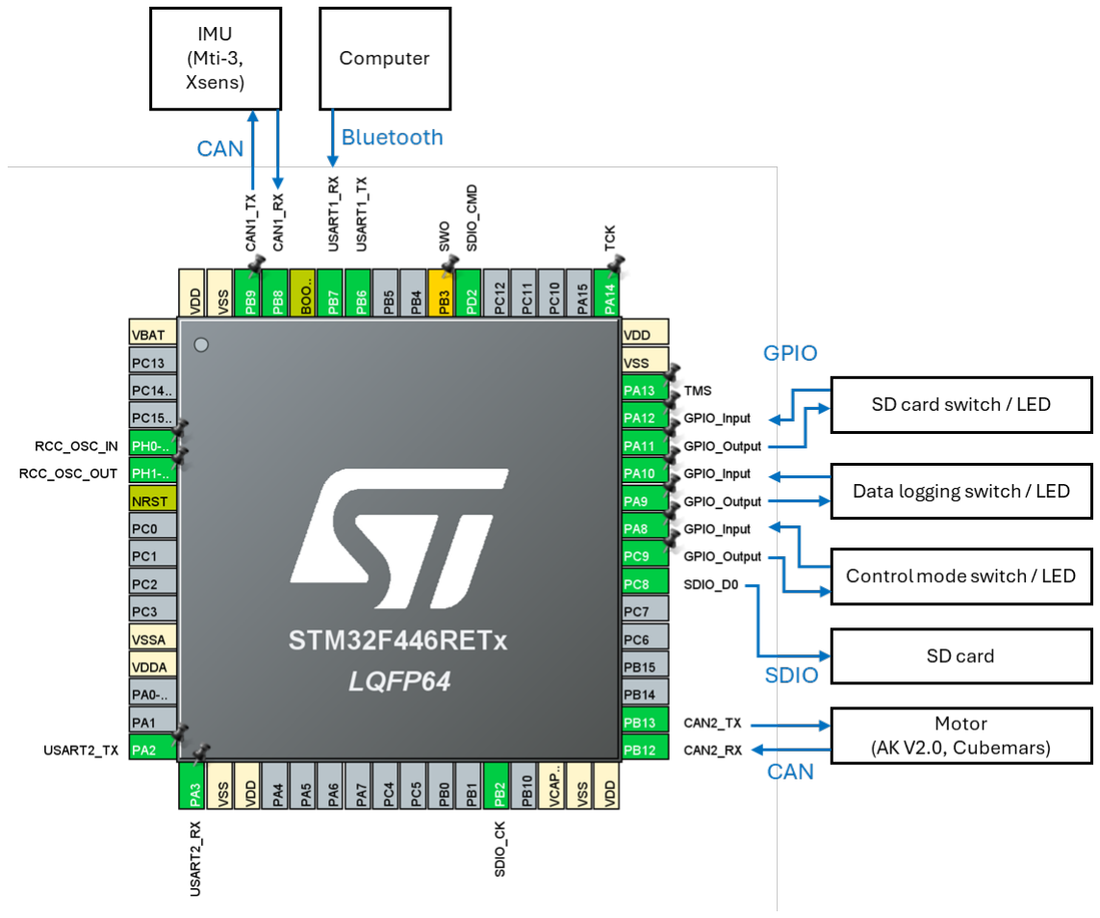
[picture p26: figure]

## Import, build, and flash the firmware

The firmware runs on the STM32, not on the host PC. Use the following procedure to program the controller:
1. Clone the repository. Clone OpenHi-P-Exo and open the Controller directory.

### 2. Import the project. In STM32CubeIDE, select File > Import > Existing Projects

into Workspace and choose the Controller directory.
3. Build. Select the Debug or Release configuration and build the project.

### 4. Connect ST-LINK. Connect the NUCLEO-F446RE to the PC through the onboard

ST-LINK USB connector.

### 5. Flash and test. Use Run or Debug to program the MCU. Confirm that the firmware

starts without build or connection errors.
The peripheral configuration is stored in Open Hip Exo.ioc. If STM32CubeMX is used to regenerate source files, application changes should remain inside the generated USER CODE regions.

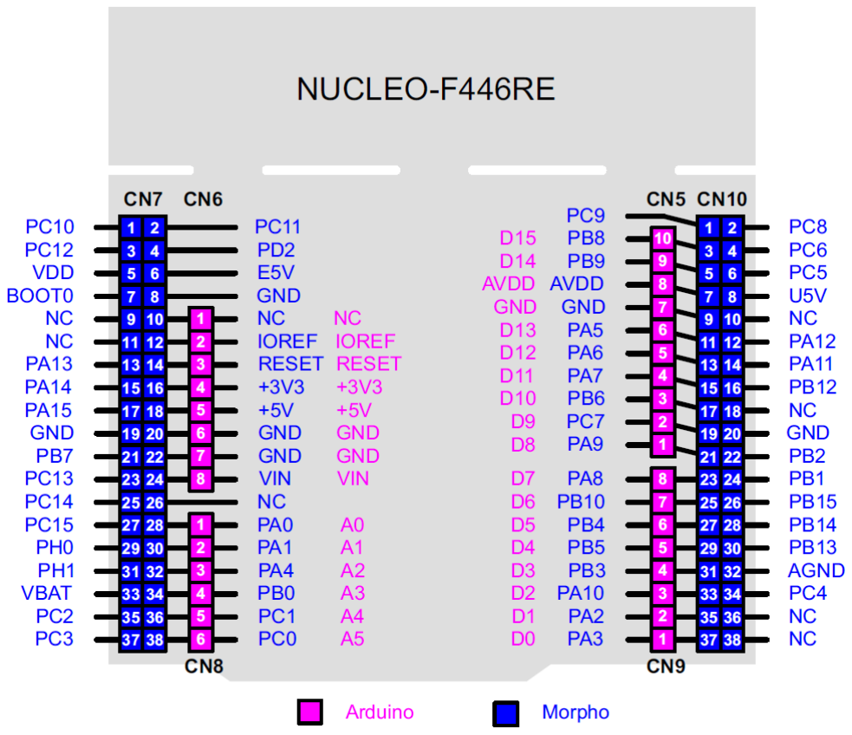
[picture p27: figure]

## IMU and CAN interface

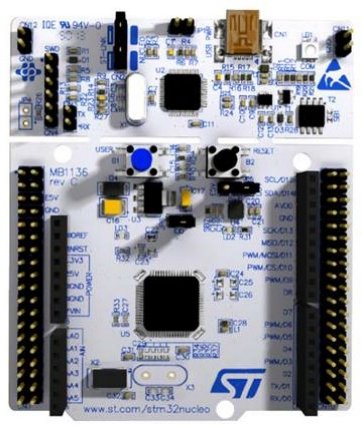
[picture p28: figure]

The OpenHi-P system uses an Xsens MTi-3 attitude and heading reference system on each leg. The sensor combines a three-axis gyroscope, accelerometer, and magnetometer with onboard sensor fusion. It provides orientation (roll, pitch, and yaw), linear acceleration, and angular-rate measurements. Left-leg frames use the 0x300 block, right-leg the 0x500 block.
Signal | Left-leg CAN IDs | Right-leg CAN IDs | Values stored by the STM32
Orientation | 0x311-0x312 | 0x511-0x512 | Roll, pitch, yaw
Acceleration | 0x313-0x314 | 0x513-0x514 | AccX, AccY, AccZ
Angular rate | 0x315-0x316 | 0x515-0x516 | GyroX, GyroY, GyroZ

CAN ID (left / right) | Bytes 0-3 | Bytes 4-7 | Encoding
0x311 / 0x511 | Roll | Pitch | float32, big-endian
0x312 / 0x512 | Yaw | - | float32, big-endian
0x313 / 0x513 | AccX | AccY | float32, big-endian
0x314 / 0x514 | AccZ | - | float32, big-endian
0x315 / 0x515 | GyroX | GyroY | float32, big-endian
0x316 / 0x516 | GyroZ | - | float32, big-endian
Datasheet and integration references: (https://www.xsens.com/hubfs/Downloads/Leaflets/MTi-3.pdf) Xsens MTi-3 product sheet; (https://www.xsens.com/hubfs/Downloads/Leaflets/MTi-3.pdf) Xsens MTi 1-series hardware documentation. (https://mtidocs.xsens.com/general-information-2)

## Actuator and CAN interface

Each hip joint is driven by a CubeMars AK10-9 V2.0 actuator. The actuator integrates a brushless motor, a 9:1 planetary gearbox, position sensing, and a motor driver. The embedded driver closes the inner motor-current loop, while the STM32 calculates the current command needed to produce the desired hip torque.
Command and feedback flow between the STM32 and the motor:

### 1. Generate desired torque. The gait controller evaluates the active torque profile for

the current gait phase.

### 2. Convert torque to current. The current controller uses the torque constant and

gear ratio, then adds torque-error feedback and motor-speed damping. The sign is adjusted for the left and right actuators.

### 3. Send the CAN2 command. At up to 500 Hz, the STM32 sends an extended CAN

frame to motor ID 0 (right) or motor ID 1 (left). The four-byte payload stores current in amperes multiplied by 1000.
4. Read motor feedback. The actuator returns position, electrical speed, current, temperature, and an error code. The STM32 uses these values for control, logging, and safety checks.

Item | OpenHi-P configuration
Power | 22.2 V nominal actuator supply from the 6S battery pack (25.2 V full charge); the AK 2.0 driver manual specifies an 18-52 V input range.
CAN connection | CAN2 on PB12 (RX) and PB13 (TX), through the CAN transceiver; 1 Mbit/s; extended frames.
Current command | Extended ID = motor_id | (1 << 8); four-byte signed current command, current [A] x 1000.
Periodic feedback | Extended ID = 0x2900 + motor_id; eight bytes for position, speed, current, temperature, and error code.
Motor IDs | 0 = right actuator; 1 = left actuator.
Before enabling assistance, configure unique motor IDs, select servo mode, set the CAN rate to match the controller, and enable periodic status feedback. The firmware sends zero current when control mode is off or gait has not been detected. It also stops assistance when the configured current, torque, or temperature limits are exceeded. Datasheet and setup references: (https://www.cubemars.com/product/ak10-9-v2-0-kv60-robotic-actuator.html) CubeMars AK10-9 V2.0 product page; (https://www.cubemars.com/product/ak10-9-v2-0-kv60-robotic-actuator.html) AK 2.0 series driver manual. (https://www.cubemars.com/data/cms/202605/ak-series-driver-manual-v1-0-18-for-ak-2-0-robotic-actuator.pdf)

## Power distribution and grounding

The exoskeleton runs from a single lithium-polymer battery pack (ELE-5). The pack feeds two branches: an unregulated actuator bus and a regulated logic bus.
1. Actuator bus. Both actuators are supplied directly from the pack: 22.2 V nominal, 25.2 V full charge (ELE-5, 6S LiPo). The AK 2.0 driver accepts 18-52 V. Set the low-voltage cutoff at 3.2 V per cell (19.2 V), since 3.0 V per cell reaches the 18 V driver minimum.

### 2. Logic bus. A buck regulator converts the pack voltage to 5 V for the NUCLEO-

F446RE. It must accept the full pack range and supply at least 1 A. The build uses a Pololu D24V22F5 (6.5-36 V in, 5 V 2.5 A); any equivalent may be substituted.

### 3. Board and sensor rails. The 5 V enters the Nucleo at E5V (CN7 pin 6; ground

CN7 pin 8). Set JP5 to position 2-3 and leave JP1 open. The onboard regulator then supplies 3.3 V to the HM-10, the sensor interface, and the MTi-3 sensors. ST-LINK USB may stay connected while powered from E5V.

### 4. Grounding. Tie pack negative, regulator ground, Nucleo GND, CAN transceiver

grounds, and HM-10 ground to a single common ground. Both CAN buses and the HM-10 UART link require it.

Rail | Source | Nominal voltage | Loads
Actuator bus | Battery pack (ELE-5) | 22.2 V nominal (25.2 V full charge; driver range 18-52 V) | AK10-9 V2.0 actuators (x2)
Logic bus | Buck regulator from the pack | 5 V | NUCLEO-F446RE, through E5V
Logic 3.3 V | Nucleo onboard regulator | 3.3 V | HM-10, MTi-3, sensor interface, CAN transceivers

## Bluetooth module setup

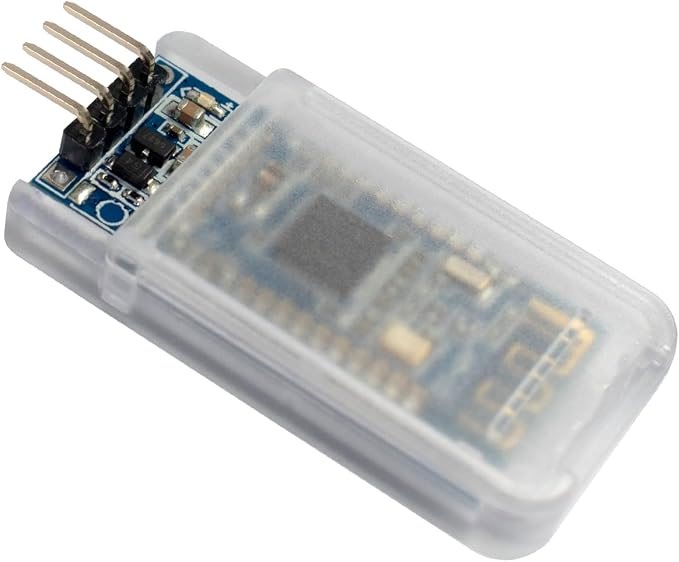
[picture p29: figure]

The HM-10 module provides a wireless serial link between the host PC and USART1 on the STM32. The module contains its own BLE firmware and acts only as a BLE-to-UART bridge.

The following items are required to configure and test the HM-10 module:
- HM-10 BLE module
- USB-to-UART converter
- Jumper wires
The USB-to-UART converter is used only to configure and test the HM-10 module. During exoskeleton operation, the HM-10 is connected directly to the STM32 controller.

Connect the module to a PC through a 3.3 V USB-to-UART converter. Begin at the module default baud rate, which is commonly 9600 baud, and enter AT-command mode. First send AT and confirm an OK response. Then configure the BLE name and UART baud rate so they match the host optimizer and STM32 firmware.

AT
AT+NAMEHIP_EXO_MAIN
AT+BAUD4

The module should return an OK response after the initial AT command. The remaining commands set the BLE device name to HIP_EXO_MAIN and configure the UART baud rate to 115200 baud. After changing the baud rate, reconnect the serial terminal at 115200 baud and send AT again to confirm that communication still works.

## Wiring the HM-10 to the STM32

After configuration, connect the HM-10 to the NUCLEO-F446RE as shown below.

HM-10 pin | STM32 connection
VCC | 3.3 V
GND | GND
TXD | PB7 / USART1_RX
RXD | PB6 / USART1_TX

Both devices must share the same ground. The HM-10 used in this system operates with 3.3 V logic and should be connected to the 3.3 V supply of the controller.

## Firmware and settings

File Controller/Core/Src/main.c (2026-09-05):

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
/* Includes ------------------------------------------------------------------*/
#include "main.h"
#include "can.h"
#include "dma.h"
#include "fatfs.h"
#include "sdio.h"
#include "tim.h"
#include "usart.h"
#include "gpio.h"

/* USER CODE BEGIN Includes */
#include <math.h>
#include <string.h>
#include <stdio.h>
#include <stdlib.h>
#include <stdbool.h>

#include "globals.h"
#include "servo_sending.h"
#include "servo_receiving.h"
#include "sd_card.h"
#include "torque_profile.h"
#include "torque_calculation.h"
#include "can_rx_callback.h"
#include "control_logic.h"
#include "motor_control.h"

/* USER CODE END Includes */


/* USER CODE BEGIN PV */

// Tx Data (MCU -> SD Card; SDIO)
TxData dataToSave = {0};
uint8_t paddedTxData[sizeof(TxData) + 4];

// Rx Data (PC -> MCU; BLE)
uint8_t rxDataBLE[RX_BYTES];

/* Torque Profile -----------------------------------------------*/
TorqueProfile profile;

/* Clock and Timer -----------------------------------------------*/
float timeSec = 0.0f;
uint16_t initCnt = 0;

const float initializationTime = 2.0f;
const float calibrationTime = 3.0f;

const uint16_t systemFrequency = 1000; // [Hz]
const uint16_t imuFrequency = 100;	   // [Hz]
const uint16_t motorFrequency = 500;   // [Hz]

/* Sensor Data -----------------------------------------------*/
float loadRight = 0;
float loadLeft = 0;

float voltageSumLeft = 0.0f;
float voltageSumRight = 0.0f;

float imuAngleSumLeft = 0.0f;
float imuAngleSumRight = 0.0f;

float voltageMeanLeft = 0.0f;
float voltageMeanRight = 0.0f;

float imuMeanLeft = 0.0f;
float imuMeanRight = 0.0f;

/* Current Control - AK10-9 -----------------------------------------------*/
float G = 9.0f;
float k_t = 0.12f;
float k_p = 2.0f;
float k_d = 1.0f;

/* Control State Machine -----------------------------------------------*/
uint8_t controlMode = 0; // 0: mode off, 1: mode on;

bool walkingFlagLeft = false;
bool walkingFlagRight = false;

bool eStop = false;
bool motorConnected = true;

const float motorCurLimit = 60.0f; // [A]
const float torqueUpperLimit = 27.0f;
const float torqueLowerLimit = -48.0f;
const float temperatureLimit = 55.0f;

bool newBLEDataFlag = false;

/* USER CODE END PV */

void SystemClock_Config(void);
/* USER CODE BEGIN 0 */

// Rx Data (PC -> MCU; BLE)
void HAL_UART_RxCpltCallback(UART_HandleTypeDef *huart)
{
	if (huart->Instance == USART1)
	{
		newBLEDataFlag = true;
	}
}

void process_ble_data(void)
{
    // frame check
    if (rxDataBLE[0] != 0xAA || rxDataBLE[1] != 0xAA) return;
    if (rxDataBLE[RX_BYTES-2] != 0xBB || rxDataBLE[RX_BYTES-1] != 0xBB) return;

    float params[6];
    memcpy(params, &rxDataBLE[2], sizeof(params));

    torque_profile_set_target(params);
    torque_profile_update_trigger(&profile, timeSec);
}

// Rx Data (Motor -> MCU; CAN)
void HAL_CAN_RxFifo0MsgPendingCallback(CAN_HandleTypeDef *hcan)
{
	can_rx_callback(hcan, &dataToSave.rightLeg.imu, &dataToSave.leftLeg.imu,
					&dataToSave.rightLeg.motor, &dataToSave.leftLeg.motor);
}

void HAL_TIM_PeriodElapsedCallback(TIM_HandleTypeDef *htim)
{
	if (htim == &htim4)
	{ // 1 kHz
		dataToSave.timeMsec += 1.0f;
		timeSec = dataToSave.timeMsec / 1000;

		loadLeft = dataToSave.leftLeg.imu.load;
		loadRight = dataToSave.rightLeg.imu.load;

		get_torques(loadLeft, loadRight,
					voltageMeanLeft, voltageMeanRight,
					&dataToSave.leftLeg.torqueMeasured, &dataToSave.rightLeg.torqueMeasured);

		if (timeSec > initializationTime && timeSec <= initializationTime + calibrationTime)
		{ // After initialization, Start Calibration

			if ((int)dataToSave.timeMsec % (systemFrequency / imuFrequency) == 0)
			{ // 100 Hz
				initCnt++;

				imuAngleSumLeft += dataToSave.leftLeg.imu.roll;
				imuAngleSumRight += dataToSave.rightLeg.imu.roll;

				voltageSumLeft += loadLeft * 3.3f / 4095;
				voltageSumRight += loadRight * 3.3f / 4095;
			}

			if (initCnt == imuFrequency * (int)calibrationTime)
			{
				imuMeanLeft = imuAngleSumLeft / initCnt;
				imuMeanRight = imuAngleSumRight / initCnt;

				voltageMeanLeft = voltageSumLeft / initCnt;
				voltageMeanRight = voltageSumRight / initCnt;

				initCnt = 0;
				imuAngleSumLeft = 0.0f;
				imuAngleSumRight = 0.0f;
				voltageSumLeft = 0.0f;
				voltageSumRight = 0.0f;
			}
		}

		if (timeSec > initializationTime + calibrationTime)
		{ // After Calibration, Start Control
			if ((int)dataToSave.timeMsec % (systemFrequency / motorFrequency) == 0)
			{ // 500 Hz

				if (fabsf(dataToSave.leftLeg.motor.Current) > motorCurLimit || fabsf(dataToSave.rightLeg.motor.Current) > motorCurLimit || dataToSave.leftLeg.torqueMeasured <= torqueLowerLimit || dataToSave.leftLeg.torqueMeasured >= torqueUpperLimit || dataToSave.rightLeg.torqueMeasured <= torqueLowerLimit || dataToSave.rightLeg.torqueMeasured >= torqueUpperLimit || dataToSave.leftLeg.motor.Temp >= temperatureLimit || dataToSave.rightLeg.motor.Temp >= temperatureLimit)
				{
					eStop = true;

					comm_can_set_current(motor_ids[0], 0);
					comm_can_set_current(motor_ids[1], 0);
				}

				if (!eStop && motorConnected)
				{
					if ((controlMode == 1) && ((walkingFlagLeft && walkingFlagRight)))
					{

						motor_current_control(motor_ids[1],
											  dataToSave.leftLeg.torqueDesired,
											  dataToSave.leftLeg.torqueMeasured,
											  dataToSave.leftLeg.motor.Speed,
											  true);

						motor_current_control(motor_ids[0],
											  dataToSave.rightLeg.torqueDesired,
											  dataToSave.rightLeg.torqueMeasured,
											  dataToSave.rightLeg.motor.Speed,
											  false);
					}
					else
					{
						comm_can_set_current(motor_ids[0], 0);
						comm_can_set_current(motor_ids[1], 0);
					}
				}
			}

			if ((int)dataToSave.timeMsec % (systemFrequency / imuFrequency) == 0)
			{ // 100 Hz

				if (newBLEDataFlag)
				{
					newBLEDataFlag = false;
					process_ble_data();			
				}
				
				torque_profile_update_continuous(&profile, timeSec);

				main_controller(timeSec,
								imuMeanLeft, imuMeanRight,
								&dataToSave.leftLeg.imu, &dataToSave.rightLeg.imu,
								&dataToSave.leftLeg.gaitCycleNorm, &dataToSave.rightLeg.gaitCycleNorm,
								&walkingFlagLeft, &walkingFlagRight,
								&profile,
								&dataToSave.leftLeg.torqueDesired, &dataToSave.rightLeg.torqueDesired);

				// Data Save
				memcpy(&paddedTxData[2], &dataToSave, sizeof(TxData));

				// Transmit Data to SD Card via SDIO (MCU)
				if (logState == 2)
				{
					write_data_to_sd((uint8_t *)&paddedTxData);
				}
			}
		}
	}
}

/* USER CODE END 0 */

/**
  * @brief  The application entry point.
  * @retval int
  */
int main(void)
{

  /* MCU Configuration--------------------------------------------------------*/

  /* Reset of all peripherals, Initializes the Flash interface and the Systick. */
  HAL_Init();

  /* Configure the system clock */
  SystemClock_Config();

  /* Initialize all configured peripherals */
  MX_GPIO_Init();
  MX_DMA_Init();
  MX_USART2_UART_Init();
  MX_SDIO_SD_Init();
  MX_TIM4_Init();
  MX_FATFS_Init();
  MX_CAN1_Init();
  MX_USART1_UART_Init();
  MX_CAN2_Init();
  /* USER CODE BEGIN 2 */

	HAL_CAN_Start(&hcan1);
	HAL_CAN_ActivateNotification(&hcan1, CAN_IT_RX_FIFO0_MSG_PENDING);

	HAL_CAN_Start(&hcan2);
	HAL_CAN_ActivateNotification(&hcan2, CAN_IT_RX_FIFO0_MSG_PENDING);

	HAL_UART_Receive_DMA(&huart1, rxDataBLE, RX_BYTES);

	HAL_TIM_Base_Start_IT(&htim4);

	if (motorConnected)
	{
		for (int i = 0; i < MOTOR_COUNT; i++)
		{
			enter_motor_mode_servo(motor_ids[i]);
			comm_can_set_origin(motor_ids[i], 0);
		}
	}

	torque_profile_init(&profile);

	paddedTxData[0] = 0xAA;
	paddedTxData[1] = 0xAA;
	paddedTxData[sizeof(paddedTxData) - 2] = 0xBB;
	paddedTxData[sizeof(paddedTxData) - 1] = 0xBB;

  /* USER CODE END 2 */

  /* Infinite loop */
  /* USER CODE BEGIN WHILE */
	while (1)
	{
		sd_card_task();
		update_control_mode(&controlMode);
	}
    /* USER CODE END WHILE */

}

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


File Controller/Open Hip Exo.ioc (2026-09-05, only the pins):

Mcu.UserName=STM32F446RETx
PA10.Signal=GPIO_Input
PA11.Signal=GPIO_Output
PA12.Signal=GPIO_Input
PA13.GPIO_Label=TMS
PA13.Signal=SYS_JTMS-SWDIO
PA14.GPIO_Label=TCK
PA14.Signal=SYS_JTCK-SWCLK
PA2.Signal=USART2_TX
PA3.Signal=USART2_RX
PA8.Signal=GPIO_Input
PA9.Signal=GPIO_Output
PB12.Signal=CAN2_RX
PB13.Signal=CAN2_TX
PB2.Signal=SDIO_CK
PB3.GPIO_Label=SWO
PB3.Signal=SYS_JTDO-SWO
PB6.Signal=USART1_TX
PB7.Signal=USART1_RX
PB8.Signal=CAN1_RX
PB9.Signal=CAN1_TX
PC8.Signal=SDIO_D0
PC9.Signal=GPIO_Output
PD2.Signal=SDIO_CMD
PH0-OSC_IN.Signal=RCC_OSC_IN
PH1-OSC_OUT.Signal=RCC_OSC_OUT

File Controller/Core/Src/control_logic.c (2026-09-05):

#include <math.h>
#include <string.h>
#include <stdlib.h>
#include <stdbool.h>
#include <stdint.h>
#include "stm32f4xx_hal.h"

#include "control_logic.h"
#include "torque_profile.h"

void update_control_mode(uint8_t *controlMode)
{
	if (!HAL_GPIO_ReadPin(GPIOA, GPIO_PIN_8))
	{
		HAL_GPIO_WritePin(GPIOC, GPIO_PIN_9, GPIO_PIN_RESET);
		*controlMode = 0;
	}
	else
	{
		HAL_GPIO_WritePin(GPIOC, GPIO_PIN_9, GPIO_PIN_SET);
		*controlMode = 1;
	}
}

#define IMU_SMOOTH_NUM 30 // 100 Hz - 0.3 s

#define STEP_TRACK_NUM 3

// Left
static float angleRawArrayLeft[IMU_SMOOTH_NUM] = {0};
static float velocityRawArrayLeft[IMU_SMOOTH_NUM] = {0};
static float angleFiltArrayLeft[2] = {0};
static float velocityFiltArrayLeft[2] = {0};
static float phaseAngleFiltLeft = 0.0f;
static float phaseAngleFiltPrevLeft = 0.0f;
static float angleSmoothArrayLeft[3] = {0};
static float velocitySmoothArrayLeft[3] = {0};
static float phaseAngleSmoothLeft = 0.0f;
static float phaseAngleSmoothPrevLeft = 0.0f;

static uint16_t istrideLeft = 0;
static float stepPrevTimeLeft = 0.0f;
static float stepDurationsLeft[STEP_TRACK_NUM] = {0};
static bool startMoveFlagLeft = false;
static float walkingStopTimeLeft = 0.0f;
static bool noMoveFlagLeft = false;
static float noMoveTimeLeft = 0.0f;
static bool phaseFiltDropFlagLeft = false;
static float phaseFiltDropTimeLeft = 0.0f;

static bool angleMinFlagLeft = true;
static bool angleMaxFlagLeft = false;
static bool velocityMinFlagLeft = true;
static bool velocityMaxFlagLeft = false;

static float angleMinLeft = 0.0f;
static float angleMaxLeft = 0.0f;
static float angleCenterFactorLeft = 0.0f;
static float angleSizeFactorLeft = 100.0f;
static float angleNormLeft = 0.0f;

static float velocityMinLeft = 0.0f;
static float velocityMaxLeft = 0.0f;
static float velocityCenterFactorLeft = 0.0f;
static float velocitySizeFactorLeft = 100.0f;
static float velocityNormLeft = 0.0f;

static float phaseAngleNormLeft = 0.0f;
static float phaseRadiusLeft = 0.0f;

// Right
static float angleRawArrayRight[IMU_SMOOTH_NUM] = {0};
static float velocityRawArrayRight[IMU_SMOOTH_NUM] = {0};
static float angleFiltArrayRight[2] = {0};
static float velocityFiltArrayRight[2] = {0};
static float phaseAngleFiltRight = 0.0f;
static float phaseAngleFiltPrevRight = 0.0f;
static float angleSmoothArrayRight[3] = {0};
static float velocitySmoothArrayRight[3] = {0};
static float phaseAngleSmoothRight = 0.0f;
static float phaseAngleSmoothPrevRight = 0.0f;

static uint16_t istrideRight = 0;
static float stepPrevTimeRight = 0.0f;
static float stepDurationsRight[STEP_TRACK_NUM] = {0};

static bool startMoveFlagRight = false;
static float walkingStopTimeRight = 0.0f;
static bool noMoveFlagRight = false;
static float noMoveTimeRight = 0.0f;
static bool phaseFiltDropFlagRight = false;
static float phaseFiltDropTimeRight = 0.0f;

static bool angleMinFlagRight = true;
static bool angleMaxFlagRight = false;
static bool velocityMinFlagRight = true;
static bool velocityMaxFlagRight = false;

static float angleMinRight = 0.0f;
static float angleMaxRight = 0.0f;
static float angleCenterFactorRight = 0.0f;
static float angleSizeFactorRight = 100.0f;
static float angleNormRight = 0.0f;

static float velocityMinRight = 0.0f;
static float velocityMaxRight = 0.0f;
static float velocityCenterFactorRight = 0.0f;
static float velocitySizeFactorRight = 100.0f;
static float velocityNormRight = 0.0f;

static float phaseAngleNormRight = 0.0f;
static float phaseRadiusRight = 0.0f;

void process_leg(float timeSec, float imuMean, IMUData *imuData, float *gaitCycleNorm,
				 bool *walkingFlag, TorqueProfile *profile, float *torqueDesired,
				 bool *startMoveFlag, bool *noMoveFlag,
				 bool *angleMinFlag, bool *angleMaxFlag,
				 bool *velocityMinFlag, bool *velocityMaxFlag,
				 float *walkingStopTime, float *noMoveTime,
				 float *angleRawArray, float *velocityRawArray,
				 float *angleFiltArray, float *velocityFiltArray,
				 float *phaseAngleFilt, float *phaseAngleFiltPrev,
				 float *angleSmoothArray, float *velocitySmoothArray,
				 float *phaseAngleSmooth, float *phaseAngleSmoothPrev,
				 float *angleMin, float *angleMax,
				 float *angleCenterFactor, float *angleSizeFactor,
				 float *velocityMin, float *velocityMax,
				 float *velocityCenterFactor, float *velocitySizeFactor,
				 float *angleNorm, float *velocityNorm,
				 float *phaseAngleNorm, float *phaseRadius,
				 float *stepPrevTime, float *stepDurations,
				 bool *phaseFiltDropFlag, float *phaseFiltDropTime,
				 uint16_t *istride)
{

	const float startMoveVelThreshold = 0.7f;
	const float noMoveVelThreshold = 0.3f;
	const float noMoveTimeThreshold = 0.5f; // [s]
	const float velocityPeakThreshold = 1.0f;
	const float radiusThreshold = 0.4f;
	const float pauseTimeThreshold = 1.0f; // [s]

	const uint16_t freqSampling = 100;
	const uint16_t freqCutoff = 7;
	const float T = 1.0f / freqSampling;
	const float cutoff = 2.0f * (float)M_PI * freqCutoff;
	const float a = cutoff / (2.0f / T + cutoff);
	const float b = a;
	const float c = (2.0f / T - cutoff) / (2.0f / T + cutoff);

	float angleRaw, velocityRaw;

	angleRaw = imuData->roll - imuMean;	
	velocityRaw = -imuData->gyroX;

	// Shifting Raw Data
	for (uint8_t i = 0; i < IMU_SMOOTH_NUM - 1; i++)
	{
		angleRawArray[i] = angleRawArray[i + 1];
		velocityRawArray[i] = velocityRawArray[i + 1];
	}

	angleRawArray[IMU_SMOOTH_NUM - 1] = angleRaw;
	velocityRawArray[IMU_SMOOTH_NUM - 1] = velocityRaw;

	angleFiltArray[1] = a * angleRawArray[IMU_SMOOTH_NUM - 1] + b * angleRawArray[IMU_SMOOTH_NUM - 2] + c * angleFiltArray[0];
	velocityFiltArray[1] = a * velocityRawArray[IMU_SMOOTH_NUM - 1] + b * velocityRawArray[IMU_SMOOTH_NUM - 2] + c * velocityFiltArray[0];

	angleFiltArray[0] = angleFiltArray[1];
	velocityFiltArray[0] = velocityFiltArray[1];

	*phaseAngleFilt = atan2f(velocityFiltArray[1], angleFiltArray[1] - *angleCenterFactor);
	if (*phaseAngleFilt < 0.0f)
		*phaseAngleFilt += 2.0f * (float)M_PI;

	// Summing Raw Data
	float sumAng = 0.0f;
	float sumVel = 0.0f;

	for (uint8_t i = 0; i < IMU_SMOOTH_NUM; i++)
	{
		sumAng += angleRawArray[i];
		sumVel += velocityRawArray[i];
	}

	// Smoothing - Average
	float angleSmooth = sumAng / (float)IMU_SMOOTH_NUM;
	float velocitySmooth = sumVel / (float)IMU_SMOOTH_NUM;

	for (uint8_t i = 0; i < 2; i++)
	{
		angleSmoothArray[i] = angleSmoothArray[i + 1];
		velocitySmoothArray[i] = velocitySmoothArray[i + 1];
	}

	angleSmoothArray[2] = angleSmooth;
	velocitySmoothArray[2] = velocitySmooth;

	*phaseAngleSmooth = atan2f(velocitySmooth, angleSmooth - *angleCenterFactor);

	if (*phaseAngleSmooth < 0.0f)
		*phaseAngleSmooth += 2.0f * (float)M_PI;

	// Walking Start Detection
	if (fabsf(velocitySmooth) > startMoveVelThreshold && (timeSec - *walkingStopTime) > pauseTimeThreshold)
	{
		*startMoveFlag = true;
	}
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

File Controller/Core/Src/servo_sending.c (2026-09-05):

#include "servo_sending.h"
#include "stm32f4xx_hal.h"

extern CAN_HandleTypeDef hcan2; // This is a global variable that represents the CAN1 peripheral.
CAN_TxHeaderTypeDef Tx0Header;  // Structure that defines the parameters of a CAN Tx message header.
uint32_t Tx0Mailbox;            // Mailbox identifier

extern uint8_t buffer[8]; // Buffer for CAN data

// Sends a CAN frame with a given ID, data, and data length. This function is often used in the context of CANopen protocols.
// The ID is the identifier of the message (which usually indicates its purpose) and the data is an array of bytes to be sent.
// The function first sets the various properties of the CAN message header, and then sends the message using the HAL_CAN_AddTxMessage function.
// If all the transmit mailboxes are full, it waits until there is space to transmit.

void sendFrameEXTId(uint16_t ID, uint8_t *data, uint8_t len)
{

  // Setting the CAN message properties
  Tx0Header.ExtId = ID;
  Tx0Header.RTR = CAN_RTR_DATA;
  Tx0Header.IDE = CAN_ID_EXT;
  Tx0Header.DLC = len;

  // Waiting for a free Tx mailbox
  uint32_t startTime = HAL_GetTick();
  while (HAL_CAN_GetTxMailboxesFreeLevel(&hcan2) == 0)
  {
    if ((HAL_GetTick() - startTime) > 20)
    {
      return;
    }
  }
  // Sending the message
  HAL_CAN_AddTxMessage(&hcan2, &Tx0Header, data, &Tx0Mailbox);

  // Waiting for the message to be transmitted
  startTime = HAL_GetTick();
  while (HAL_CAN_IsTxMessagePending(&hcan2, Tx0Mailbox) == 1)
  {
    if ((HAL_GetTick() - startTime) > 20)
    {
      return;
    }
  }
}

// These functions are used to configure a motor to enter or exit servo mode.
// Reference: https://tmotorcancontrol.readthedocs.io/en/latest/_modules/TMotorCANControl/servo_can.html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
void servo_motor_initialize(uint16_t ID)
{
  enter_motor_mode_servo(ID);
  comm_can_set_origin(ID, 0);
}

void enter_motor_mode_servo(uint8_t controller_id)
{
  buffer[0] = 0xFF;
  buffer[1] = 0xFF;
  buffer[2] = 0xFF;
  buffer[3] = 0xFF;
  buffer[4] = 0xFF;
  buffer[5] = 0xFF;
  buffer[6] = 0xFF;
  buffer[7] = 0xFC;
  sendFrameEXTId(controller_id, buffer, 8);
}

void exit_motor_mode_servo(uint8_t controller_id)
{
  buffer[0] = 0xFF;
  buffer[1] = 0xFF;
  buffer[2] = 0xFF;
  buffer[3] = 0xFF;
  buffer[4] = 0xFF;
  buffer[5] = 0xFF;
  buffer[6] = 0xFF;
  buffer[7] = 0xFD;
  sendFrameEXTId(controller_id, buffer, 8);
}

// Reference: Data Sheet
// These functions append an integer value to a buffer in big-endian order.
// They take as input a pointer to the buffer, the integer to append, and a pointer to the index where the integer should be inserted.
// After appending, the index is updated to point to the next position in the buffer.
void buffer_append_int32(uint8_t *buffer, int32_t number, uint8_t *index)
{
  buffer[(*index)++] = number >> 24;
  buffer[(*index)++] = number >> 16;
  buffer[(*index)++] = number >> 8;
  buffer[(*index)++] = number;
}

void buffer_append_int16(uint8_t *buffer, int16_t number, uint8_t *index)
{
  buffer[(*index)++] = number >> 8;
  buffer[(*index)++] = number;
}

// These functions send a CAN frame with a specific command to a specified controller.
// Each function constructs a command message by appending the desired value to a buffer, then sends it using the sendFrameEXTId function.
// The controller_id input determines which controller the command is sent to.
void comm_can_set_duty(uint8_t controller_id, float duty)
{
  uint8_t send_index = 0;
  uint8_t buffer[4];
  buffer_append_int32(buffer, (int32_t)(duty * 100000.0), &send_index);
  sendFrameEXTId(controller_id | ((uint32_t)CAN_PACKET_SET_DUTY << 8), buffer, send_index);
}

void comm_can_set_current(uint8_t controller_id, float current)
{ // The range -60000 ~ 60000 represents -60 ~ 60A
  uint8_t send_index = 0;
  uint8_t buffer[4];
  buffer_append_int32(buffer, (int32_t)(current * 1000.0), &send_index);
  sendFrameEXTId(controller_id | ((uint32_t)CAN_PACKET_SET_CURRENT << 8), buffer, send_index);
}

void comm_can_set_cb(uint8_t controller_id, float current)
{
  uint8_t send_index = 0;
  uint8_t buffer[4];
  buffer_append_int32(buffer, (int32_t)(current * 1000.0), &send_index);
  sendFrameEXTId(controller_id | ((uint32_t)CAN_PACKET_SET_CURRENT_BRAKE << 8), buffer, send_index);
}

void comm_can_set_rpm(uint8_t controller_id, float rpm)
{ // The range -100000 ~ 100000 represents -100000 ~ 100000 electrical speed
  uint8_t send_index = 0;
  uint8_t buffer[4];
  buffer_append_int32(buffer, (int32_t)rpm, &send_index);
  sendFrameEXTId(controller_id | ((uint32_t)CAN_PACKET_SET_RPM << 8), buffer, send_index);
}

void comm_can_set_pos(uint8_t controller_id, float pos)
{ // The range-360000000 ~ 360000000 represents position -36000° ~ 36000°
  uint8_t send_index = 0;
  uint8_t buffer[4];
  buffer_append_int32(buffer, (int32_t)(pos * 10000.0), &send_index);
  sendFrameEXTId(controller_id | ((uint32_t)CAN_PACKET_SET_POS << 8), buffer, send_index);
}

void comm_can_set_origin(uint8_t controller_id, uint8_t set_origin_mode)
{
  uint8_t buffer[1];
  buffer[0] = set_origin_mode;
  sendFrameEXTId(controller_id | ((uint32_t)CAN_PACKET_SET_ORIGIN_HERE << 8), buffer, 1);
}

void comm_can_set_pos_spd(uint8_t controller_id, float pos, int16_t spd, int16_t RPA)
{
  uint8_t send_index = 0;
  uint8_t buffer[8];
  buffer_append_int32(buffer, (int32_t)(pos * 10000.0), &send_index);
  buffer_append_int16(buffer, spd * 10, &send_index);
  buffer_append_int16(buffer, RPA * 10, &send_index);
  sendFrameEXTId(controller_id | ((uint32_t)CAN_PACKET_SET_POS_SPD << 8), buffer, send_index);
}

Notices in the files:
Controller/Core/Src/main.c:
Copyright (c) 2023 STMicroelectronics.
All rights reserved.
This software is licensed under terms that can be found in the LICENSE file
